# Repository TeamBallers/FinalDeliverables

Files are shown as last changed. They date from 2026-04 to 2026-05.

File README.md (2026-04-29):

# FinalDeliverables

The following explains the contents of this repository. Headings are directories or files located at a level associated with the size of the heading. For example, `designs` below is a first level heading and `code` below is a second level heading. `code` is a directory under `designs`.

# designs

## code
Contains all the code used in our project

### gyroscope_controller
This was used for testing the gyroscope camera cutting algorithm only. This code was not used in the final project. As it was not used in the final project, I only list relevant parts of the directory

#### camera_down_detector.py 
Contains the `CameraDownDetector` class, which was copied into the final project's `camera_client.py` file. IMU data can be passed to this class to initialize and update its readings, and can be queried for the new positions of the cameras.

#### calibrate.py
Used to get initial positions for the cameras

#### test.py
Can be run for an example of the output of the `CameraDownDetector` class

### mast3r-camera-client
This was the code ran on each of the Pis. It includes the `camera_client.py` script that captures and sends images, `camera_api.py` to start/stop the captures, `camera_api.service` to start the api on boot, and `setup.sh` to download requirements and enable the service. `downward_detector.py` contains a copy of the `CameraDownDetector` class from `gyroscope_controller`, as well as filtering classes `LogSampler` and `RatioSampler` to reduce noise from the predictions. 

### MASt3R-SLAM-API
This contains the MASt3R-SLAM code described at https://edexheim.github.io/mast3r-slam/ . Additionally, it includes a modified version of the API from the previous team at `image_receiver_api.py` and the API to run YOLO at `server/yolo_api.py`. `process_images.py` is used to run MASt3R-SLAM.

### ply_viewer
This repository contains the viewer that users will interact with. `viewer.html` contains the .ply viewer for viewing the models. `detection_popup.html` contains the viewer for live object detection.

### erms-object-detection
This repository was for testing and was not run in the final project. It includes testing infrastructure. `client_pi/test_yolo_pipeline.py` is a basic script to capture images and send them to an api that runs YOLO. The api is located in `server/yolo_api.py`. The viewer can be found in `viewer_test`.

### Usage instructions (not a directory)
Users should create a GPU VM with any Linux OS to act as the server. Install tailscale and add the server to your tailnet. In the root directory, clone `MASt3R-SLAM-API` and `ply_viewer`. In `MASt3R-SLAM-API`, follow the instructions in the `README.md` to set up your environment. 

On the three Raspberry Pis, install tailscale and add the devices to your tailnet. Clone `mast3r-camera-client`. Modify `camera_api.service` to use your server's tailnet IP. Run `bash setup.sh`. Run `sudo systemctl daemon-reload` and `sudo systemctl start camera_api.service` or reboot. 

Back on the server, find all hardcoded IPs in the html files and update them accordingly.

To run the server, use ```tailscale serve ~/ply_viewer &``` to expose the viewer files to the tailnet. Then 

```bash
cd MASt3R-SLAM-API
python image_receiver_api.py --continuous --copy ../ply_viewer/model.ply &
python server/yolo_api.py &
```

## schematics
Contains schematics and diagrams of our system, as well as 3d printing files for all stages of the project

## data
Contains various testing data used for reports

## data_sheets
Contains data sheets for purchased and used components

# reports
Contains all of our reports

# Hardware System Visuals & Measurements
Contains close-up reference images of the system and its assembly

# Videos.zip
contains a link to demo videos of our final project. Including the zip was 2GB and was taking too long.

# notebooks
contains our notebooks

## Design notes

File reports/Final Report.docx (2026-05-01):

Emergency Response Mapping Sphere

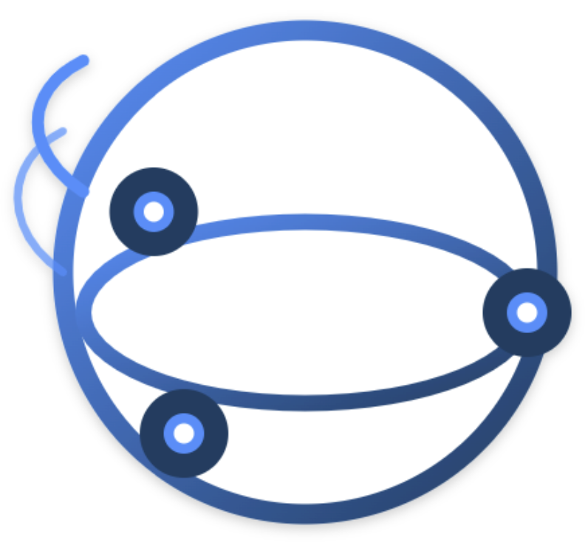
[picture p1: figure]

Final Report

Team ERMS

Brandon Le

Kiet Nguyen

Hai Yen Nguyen

Josh Wu

Antony Quach

Department of Computer Science and Engineering

Texas A&M University

Date 4/30

Table of Contents (Be sure to regenerate before submitting).

1 Executive summary (1-2 pages; 5 points) 3

1.1 Context 4

1.2 Project Goal and Objectives 4

1.3 Final Design Implementation and Pipeline 4

1.4 Project Verification Results 5

1.5 Team/Project Management 5

2 Project background (2-4 pages; 5 points) 5

2.1 Needs statement 5

2.2 Goal and objectives 5

2.3 Design constraints and feasibility 6

2.4 Literature and technical survey 6

2.5 Evaluation of alternative solutions 8

3 Final design (5-10 pages; 5 points) 9

3.1 System description 9

3.2 Complete module-wise specifications 10

3.2.1 Hardware 10

3.2.1.1 Microcontroller Operating System Setup 10

3.2.1.2 Adafruit ISM330DHCX IMU 10

3.2.1.3 Battery Selection 11

3.2.1.4 Power Distribution Board Usage 11

3.2.1.5 3D-Printed Shell 11

3.2.2 Software 11

3.2.2.1 Data Flow 11

3.2.2.2 Gyroscope and Camera Cutting 12

3.2.2.3 Master SLAM and Gaussian Splatting 12

3.2.2.4 Object Detection 12

3.2.2.5 System User Interface 13

3.3 Approach for design validation 13

4 Implementation notes (10-20 pages; 30 points) 14

4.1 System Overview 14

4.2 Mechanical Implementation: Throwable Ball Shell 14

4.2.1 Design goals and constraints 14

4.2.2 Shell geometry and layout 15

4.2.3 Camera and IMU Standoff and Mounting 15

4.2.4 Pi Mounting and Battery Support Standoffs 16

4.2.5 3D-printing process 17

4.2.6 Mechanical Assembly Procedure 18

4.3 Electrical 20

4.4 Embedded Software 20

4.4.1 Base OS and configuration 20

4.4.2 Tailscale VPN Network Setup 21

4.4.3 Camera Capture 21

4.5 Server-side 3D Model Generation and Object Detection 21

4.5.1 Data input 21

4.5.2 Object Detection Pipeline 21

4.5.3 MASt3R-SLAM Pipeline 22

4.5.4 Web-based viewer 23

4.6 Testing 23

4.7 Future Considerations 23

5 Experimental results (5-10 pages; 20 points) 24

5.1 Physical design 24

5.2 Multi-Camera Capture 25

5.3 Gyroscope and Camera cutting 26

5.4 SLAM Modeling and YOLO Object Detection 27

5.5 Camera Performance in a low-light environment 28

5.6 End-to-End System Functionality 28

6 User’s Manuals (5-10 pages; 20 points) 29

7 Course debriefing (2-4 pages; 10 points) 34

8 Budgets (2-4 pages; 5 points) 36

8.1 Detailed Cost Breakdown 36

8.2 Cost Narrative 36

8.3 Budget Comparison and Mass Production Estima 37

9 Appendices 37

10 References 37

# 1 Executive summary (1-2 pages; 5 points)

As you did with the proposal, the final report should start with an executive summary. In this section, you provide a brief overview of (1) the need, goal and objectives of the project, (2) the final design and implementation, (3) the results that were obtained, and (4) your experiences with team/project management. The intended audience of the executive summary is the program director at the institution/company that funded your project. Since the executive summary is a summary of the final report, it should be written last.

## 1.1 Context

Emergency response operations require rapid and accurate situational awareness, especially in hazardous environments where traditional methods are impractical or dangerous. First responders are routinely entering unfamiliar space such as structurally compromised buildings, active threat scenarios, and chemical spill sites, where visibility is often limited and conditions are very unpredictable. These challenges significantly increase the risk of injury, delay rescue efforts, and can lead to poor tactical decision-making in critical moments. Although current technologies such as drones, body-worn cameras, and robotic systems are used to support these operations, they frequently provide incomplete spatial information, suffer communication delays, or fail to function in confined indoor environments. Drones cannot navigate tight corridors, wheeled robots struggle with debris and rough surfaces, and stationary cameras offer limited field of vision. As a result, existing technologies do not sufficiently reduce operational risk or provide the level of real-time situational awareness necessary to ensure responder safety and mission success.

## 1.2 Project Goal and Objectives

The goal of this project is to build off of the previous team’s version of a throwable environment scanning device capable of capturing footage of an indoor environment with camera lenses and then reconstruct a 3D mapping using Gaussian splatting. Our objective includes: implementing an IMU sensor for intelligent power management by disabling ground-facing cameras, implementing SLAM algorithm for 3D reconstruction and improving accurate capturing, object detection to classify animate vs. inanimate objects, establishing WiFi connectivity for cloud-based processing, and validating performance against metrics similar to the previous team including sub-30 second deployment-to-visualization time.

Through this project, we expect that we will be able to create 3D models accurate to at least 10% of real measurements within 30 seconds of capturing images. We also plan to be able to identify and flag objects moving faster than 20 cm/s. Through these results, first responders will obtain comprehensive 3D situational awareness within seconds of deployment, enhancing tactical decision-making in active emergencies. The throwable format requires no specialized training or line-of-sight operation. Unlike 2D feeds, 3D reconstruction enables accurate spatial judgement for planning entry strategies, identifying routes, and locating victims or threats in possible hostage situations. At under $300 per unit for the throwable device using commercially available components, the system is substantially more affordable than specialized robotics, enabling broader deployment across agencies with limited resources. The server workstation can process multiple simultaneous deployments, supporting coordinated multi-room surveying. Beyond emergency responses, applications include building inspection, disaster search-and-rescue, and hazardous material incident response.

## 1.3 Final Design Implementation and Pipeline

Similar to the previous team’s design, the device consists of a spherical enclosure containing 3 wide-lens No-IR cameras inside, 3 microcontrollers consisting of a Raspberry Pi 4B and 2 Pi Zero 2 W’s, an Adafruit ISM330DHCX gyroscope module, a CMT Power Distribution module, a 5W 2.4A portable powerbank, and wireless networking that connects to a VPN. Once deployed, the operator can access the web GUI to access the model output, images with object detections, and commands to enable/disable the ball wirelessly. The shell’s design has been tweaked slightly from the previous team’s design to incorporate elements to support our changes to the hardware.

## 1.4 Project Verification Results

The product passed most of our tests regarding the reliability of the ball and its physical capabilities, but failed to provide a useful model in a satisfactory amount of time, taking about ~90 seconds in realistic usage to complete a model. It was concluded that the cameras in motion would not be able to take enough suitable photos to create a sufficient model through MASt3R-SLAM. The YOLO Object Detection exceeded our expectations, however. It was able to make important detections on live objects quickly and accurately. Even being able to make important distinctions in the dark or off of partial information. Even only a shoe is enough for the system to detect a person.

## 1.5 Team/Project Management

Throughout the project, the team followed standard engineering project-management practices, splitting into various teams focused on different tasks to develop multiple parts of the project at once, while also meeting twice a week to share progress and collaborate on ideas on how to move forward. We kept a collection of our documentation and work on a shared google drive, while pushing all project code to our shared GitHub. We also remained in constant communication via Discord.

# 2 Project background (2-4 pages; 5 points)

Describe the general scope of your project, and the specific problem that your project tackles. Go from general (e.g., search and rescue robotics) to specific (e.g., GPS navigation). This section (and all its subsections) can be expanded from those in the proposal.

## 2.1 Needs statement

Define the specific need that your project addressed. Articulate the need as an expression of dissatisfaction with the current situation. If the needs statement was revised during the semester (e.g., because the initial needs statement may have been too restrictive), please document the changes and provide a justification.

First responders routinely have to enter dangerous structures as part of their jobs. Hazards such as structural integrity, fire, or live threats slows them down during time sensitive missions and risks their lives. From 2018 to 2020, 87% of firefighter injuries occurred during structure fires, highlighting the significant dangers associated with indoor emergency response. Additionally, active shooter incidents last an average of only 12 minutes, leaving little time for responders to assess and secure a scene. Existing solutions are upwards of thousands of dollars and tend to require a skilled operator. These statistics demonstrate the urgent need for a device that first responders can deploy quickly to enhance safety and situational awareness in hazardous environments.

The previously designed Throwable Environment Scanner addresses this need but is lacking in some areas. Currently, its 3D mapping capabilities are not clear enough to allow users to be confident that all threats have been identified, demonstrating a need for improvements in threat identification. Furthermore, users may find it difficult to use the map, showing that a more intuitive user interface is needed.

## 2.2 Goal and objectives

As discussed in the proposal template, the goal is a brief, general, and ideal response to the needs statement. The need describes the current, unsatisfactory situation; the goal describes the future condition to which we aspire. The goal statement is so ideal that it would be difficult to decide when it was achieved. It rather establishes a general direction for the design mission. In contrast, the objectives are quantifiable expectations of performance. The objectives should also include a description of the conditions under which the design must perform. Again, if goal and objectives were revised during the semester, please document the changes and provide a justification for these.

The goal of this project is to enhance the Throwable Environment Scanner so that it can deliver high-quality 3D mapping directly to a first responder’s device while improving existing system efficiency.

The main objective of the system is to utilize onboard cameras to stream live video and reconstruct a 3D representation of the surrounding environment, improving situational awareness and enabling more effective threat detection. At the same time, the device must maintain its portability and durability to remain practical for field deployment. It will be limited to a maximum weight of 3 pounds and a maximum diameter of 7 inches, while also being capable of withstanding drops and collisions in hazardous conditions. The device must support 30 minutes of continuous operation at a minimum to ensure reliability during active incidents and be able to start up within 30 seconds to reduce delays. Additionally, the project must remain within cost constraints, with a maximum budget of $250 allocated for design iterations. The system must also provide threat identification in the environment to reduce mental load on users.

## 2.3 Design constraints and feasibility

Describe the constraints (e.g., technical, physical, economical, temporal) that you had to work with. Again, if these were revised during the semester, please document the changes and provide a justification.

One of the primary challenges of this project is ensuring that the first responders get an accurate representation of the environment with low latency. The 3D model generation and threat identification must take less time than traditional methods of ensuring safety in dangerous structures. Processing and reconstructing high-resolution spatial data requires significant computational resources, which may introduce latency and limit real-time usability. Additionally, the device must be engineered to withstand strong and repeated impacts, as it is designed to be thrown into hazardous environments. This requires a durable outer structure that protects internal components without exceeding weight and size constraints. Finally, the hardware must support complex transmission logic capable of delivering high-resolution images and mapping data quickly and reliably. Efficient data compression, wireless communication stability, and low-latency streaming will help maintain performance under emergency response conditions. Given that the durability and portability objectives of the system have already been tested, all objectives can be completed fully if threat detection and environment reconstruction algorithms are sufficiently fast and camera data quality is sufficiently accurate.

## 2.4 Literature and technical survey

Describe prior research and development efforts that were specifically related to your project. As stated in the proposal template, this is not meant to be a comprehensive survey of an engineering discipline, but a concise overview of the most significant results that are tightly related to your project. As a guideline, this section should include a review of not less than five commercial products or research projects. This review should conclude with a statement that explains the extent to which your final design is related to these other products/projects (e.g., is it better? or faster? or cheaper? does it target a new niche market?). Expand this section if additional references were found to be relevant during the semester.

While the Throwable Environment Scanner is not the first product to solve the problem of scouting hazardous indoor environments, it does improve on existing solutions by being cheaper and requiring little training to produce a 3D map. Other products might have one of these features, but none of them combine them all. By being cheap and requiring little training, it can be easily integrated into most teams entering dangerous rooms. The 3D model visualization can allow operators to view any aspect of the environment in just a few seconds after the ball has rolled, improving decision making.

Solution | Description | Pros | Cons
The Brinc Ball | Throwable communication device that functions as a telephone | - Capable of communicating with people inside dangerous area | - Does not record video, scan environments, or generate maps
Recon Robotics Throwbot | Compact wheeled surveillance robot for live video and audio | - Extremely durable (30-ft drops, 120-ft throws) - Up to 60 minutes of battery life | - Requires training to operate and has only one camera angle - Obstructed terrain can limit mobility
Flyability Elios 3 (Surveying Payload) | Collision-tolerant indoor drone designed for inspection, mapping, and 3D environment reconstruction | - Can actively navigate complex or obstructed spaces | - Not throwable, requires skilled operation, and is high-cost industrial hardware
Bouncing Image Explorer 360 | Throwable 360° tactical ball camera with live phone streaming (WiFi & Cellular) | - Compact, durable, and capable of window impact deployment | - No depth reconstruction (manual viewing only); high cost ($4k–$7k)
Squishy Robotics Stationary Robot | Throwable or aerial-deployable multi-sensor response device | - Highly impact-tolerant; designed for hazardous and disaster environments | - Stationary operation; complex and high-cost system

## 2.5 Evaluation of alternative solutions

Discuss the alternative designs that were considered throughout the project. Analyze the pros and cons of each of these designs, and justify your decision to opt for a particular solution. You may have found additional alternatives aside from the ones in the proposal, so make sure you include all.

- Drones
  - Pros
    - Provide overhead views of environments, including inaccessible or elevated areas.
    - Already commercially available and supported by existing technology.
  - Cons
    - Hard to operate in enclosed areas
    - Requires significant skill from a trained operator
- Grounded Robot
  - Pros
    - Can have mobility in enclosed areas
    - A lot of them carry very sophisticated mapping and recording systems
    - Already being used by some first responders and military units
  - Cons
    - Mobility issues if the ground is obstructed/uneven
    - Usually large and hard to carry. Not very portable
- Throwable Communication Ball
  - Pros
    - Cheap
    - Small
    - Durable
    - Remote communication is highly useful for many areas, not limited to search and rescue, crisis intervention, disaster response, and negotiation/de-escalation
  - Cons
    - Cannot visualize an environment
    - Requires a conscious and willing corespondent; does not work for search and rescue of unconscious people
- Body Cameras
  - Pros
    - Cheap
    - Lightweight
    - Already exists in the market
  - Cons
    - Require a human in the environment, which could be hazardous
    - Remote operators cannot can only view the direction the wearer observes
- 360° Cameras
  - Pros
    - Views the entire environment at once
    - Lightweight and portable
    - Already exists in the market
  - Cons
    - Requires a mount or transportation device to be placed somewhere

# 3 Final design (5-10 pages; 5 points)

## 3.1 System description

Please provide a description of the overall system. This description should include a high-level block diagram and a functional description of the different parts and interfaces in your final system. If any of these were revised after the CDR, please document the changes and provide a justification.

The final system is a throwable device designed to capture and reconstruct a 3D view of an environment. It is built as a spherical enclosure containing three cameras, embedded computing units (Raspberry Pi Zero 2 W and Raspberry Pi 4B), an inertial measurement unit (IMU), a battery, and a power distribution unit.

Once deployed, the cameras capture wide-angle images from different viewpoints. Each camera is connected to its own embedded unit, which handles image capture and transmits the data to a remote server. The IMU is used to determine the orientation of the device, allowing the system to identify downward-facing cameras and reduce unnecessary power consumption. The power distribution unit supplies power to all embedded components.

In the original design proposed during the Critical Design Review (CDR), a camera multiplexer was used to switch between multiple cameras on a single processor. However, this approach introduced delays due to sequential image capture. In the final design, this was replaced with multiple Raspberry Pi Zero 2 W devices and a Raspberry Pi 4B, each controlling a single camera. This allows all cameras to capture images simultaneously, improving overall system performance and image coverage.

The captured images are transmitted to a remote server through the Texas A&M IoT (TAMU IoT) network. To enable reliable and secure communication between distributed devices, the system uses Tailscale, a mesh VPN that allows each embedded unit and the server to communicate over a private network as if they were on the same local system.

On the server side, upon receiving the data, the images are synchronized and processed using 3D Gaussian Splatting to generate a 3D model of the environment. At the same time, a YOLO-based object detection model is used to identify objects within the images.

The resulting outputs, including the reconstructed 3D model and detected objects, are transmitted to an operator interface, where they can be inspected and analyzed for situational awareness and decision-making.

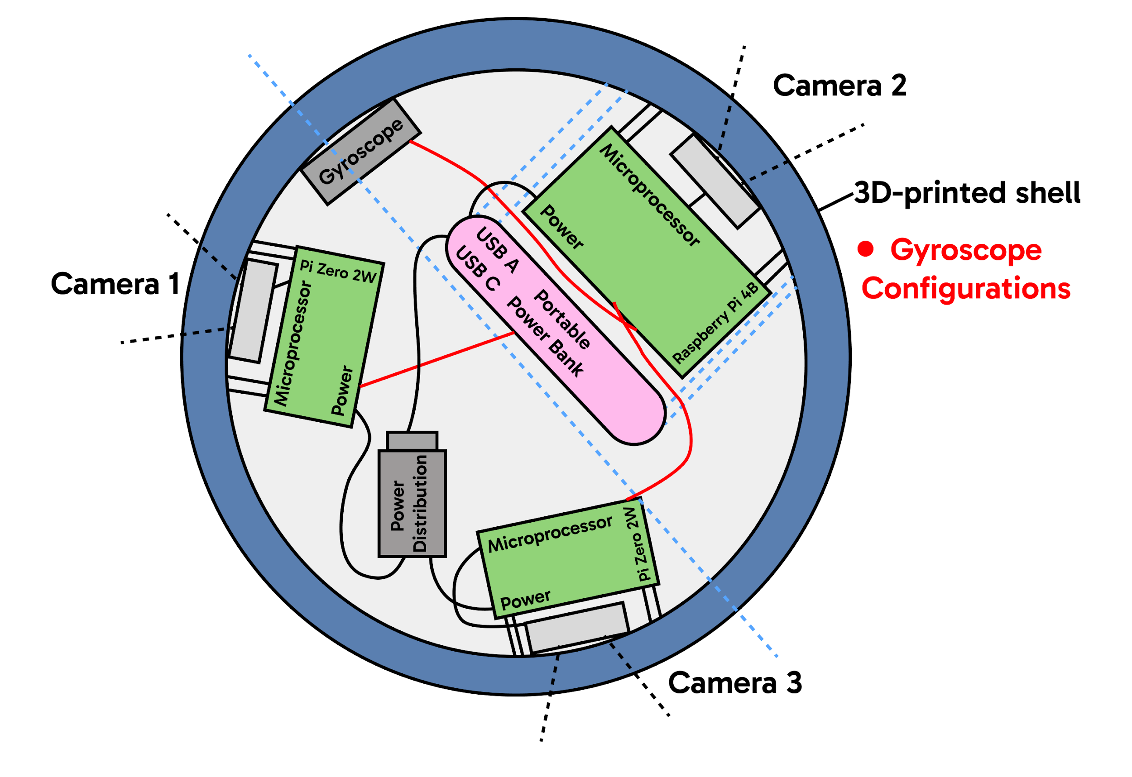
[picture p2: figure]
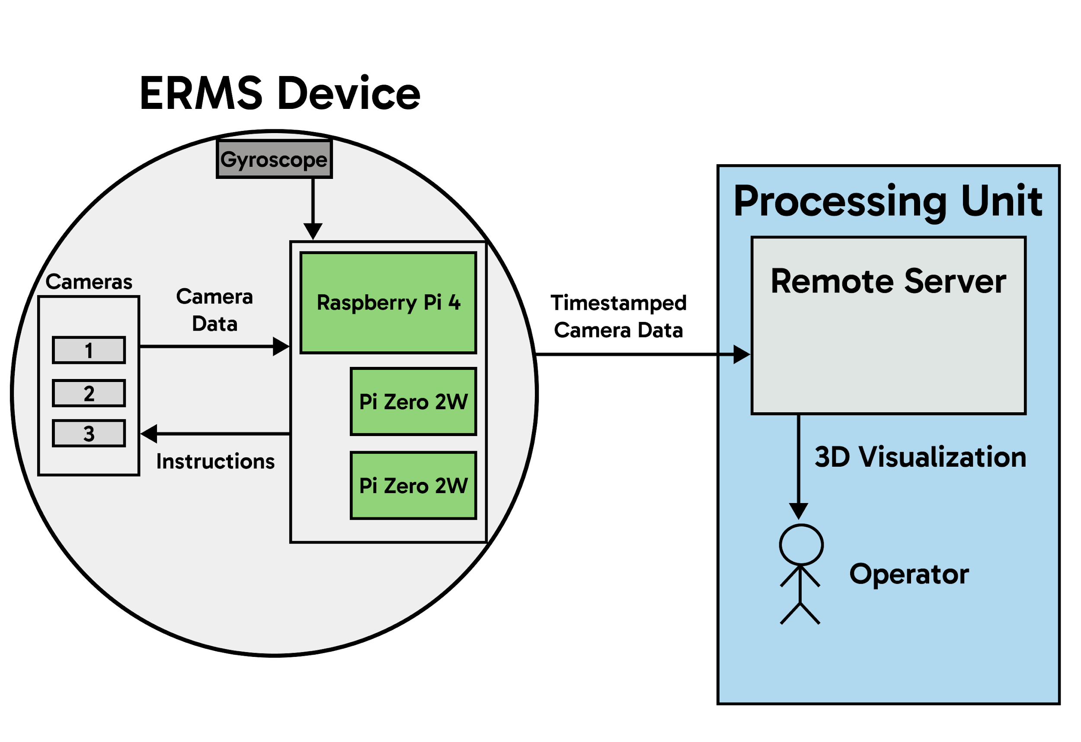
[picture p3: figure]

Figure 3.1.1: Final System High Level Diagram Figure 3.1.2. Internal layout of system

components within the spherical enclosure

## 3.2 Complete module-wise specifications

Provide a detailed design of each subsystem (both hardware and software), including

- Circuit and logic diagrams
- Interfaces and pin-outs
- Timing diagrams and waveforms
- Software processes with their inputs and outputs
- Complete parts list

If any of these were revised after the CDR, please document the changes and provide a justification.

### 3.2.1 Hardware

#### 3.2.1.1 Microcontroller Operating System Setup

The hardware architecture consists of three separate microcontrollers using a Raspberry Pi 4B, and two Raspberry Pi Zero 2 W’s. This setup ensures parallel processing and true simultaneous camera streaming to ensure environmental capturing from multiple angles at once.

#### 3.2.1.2 Adafruit ISM330DHCX IMU

The IMU is used to approximate the rotation of the ball to determine if any cameras are facing downward. If any cameras are detected to be facing downward, they are temporarily disabled and they do not upload images to the server. This helps save time and processing power, as images where the camera is facing downward are likely to not be useful.

#### 3.2.1.3 Battery Selection

The powerbank we selected was a Miady 5000mAh Mini Portable Charger, 5V 2.4A USB-C. This powerbank is able to fit nicely into the shell while providing sufficient power at 5V and 2.4 A. It is also capable of powering two devices simultaneously using both of its ports.

#### 3.2.1.4 Power Distribution Board Usage

The CMTPD Board takes an input through USB-C and regulates it to the selected voltage for output. In our case, the desired voltage output is 5V for the Raspberry Pi Zero 2W boards. We connected two micro-USB cables with pig-tailed ends directly to the output of the CMTPD Board. From there we connect the micro-USB cable to the Raspberry Pi Zero 2 W boards. This way the components are kept modular.

#### 3.2.1.5 3D-Printed Shell

The 3D-Printed Shell houses all electronic components and shields them from external forces like heat and impacts. It has 3 camera holes equidistant from one another ensuring each camera makes full use of their 120° field of vision. It uses a series of mating flanges along the equator to secure itself together. Inside, each electronic component has its own set of standoffs where each component can be secured using M2.5 screws. The standoffs for the Raspberry Pi 4B are noticeably thicker to support the larger board. Various supports are also added to prevent the internal battery from causing damage to the Raspberry Pi 4B.

### 3.2.2 Software

#### 3.2.2.1 Data Flow

The system data flow is built on a Tailscale VPN network, which establishes a secure and encrypted communication tunnel between the throwable device and the remote server. This approach enables reliable communication even when devices are connected to different Wi-Fi networks, ensuring flexibility and robustness in diverse deployment environments.

The data pipeline operates in two main stages: device-to-server data transmission and server-to-operator delivery.

On the device side, the Raspberry Pi camera units generate timestamped image frames during operation. These frames are compressed as JPEG images and downsampled to reduce bandwidth usage before being transmitted to the remote server using HTTP POST requests through a FastAPI endpoint. The server receives and stores these images in a dedicated directory, where they are monitored for downstream processing.

On the server side, incoming images are processed by two independent pipelines: a YOLO11s object detection module and a MASt3R-SLAM reconstruction pipeline. These modules operate on the same incoming dataset to generate both semantic object information and a 3D representation of the environment.

Processed outputs, including the reconstructed 3D model and annotated detection results, are served to the operator interface over HTTPS through the Tailscale network. The interface continuously polls the server for updates, enabling near real-time visualization of both spatial reconstruction and detected objects.

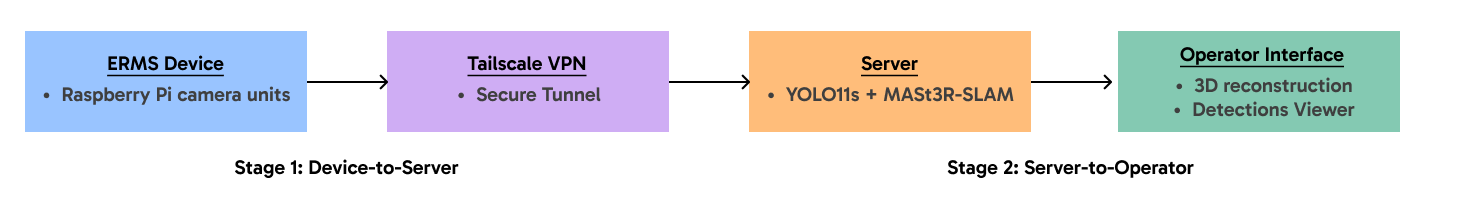
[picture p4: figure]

Figure 3.2.2.1: High-Level Diagram of Data Flow

#### 3.2.2.2 Gyroscope and Camera Cutting

The purpose of this subsystem is to detect the device’s orientation in real time using a gyroscope, enabling the system to reduce unnecessary processing and improve overall power efficiency. By identifying which camera is facing downward, the system can selectively manage image capture and processing, avoiding the use of frames that are less useful for reconstruction. The implementation relies on a gyroscope that continuously streams orientation data to the main Raspberry Pi controller over an I2C interface during operation. The controller interprets this data to compute rotation updates and determine which camera is oriented downward. It then communicates this information to the other Raspberry Pi units using a GPIO-based single-bit flag. Each Pi reads this flag during image capture and uses a timing window to assess whether its camera was facing downward during the critical portion of the capture process, allowing the system to make informed decisions about which images to retain or discard.

#### 3.2.2.3 Master SLAM and Gaussian Splatting

The MASt3R-SLAM subsystem is responsible for estimating camera motion and generating a 3D reconstruction of the environment using the captured image data. The system processes a sequence of images collected as the device moves through the environment, enabling spatial understanding of the scene.

Images are received from the capture subsystem and stored in a shared directory for processing. Using a MASt3R-SLAM implementation, the system performs feature matching across multiple images to estimate camera poses, including position and orientation for each frame. This allows the system to determine where each image was captured and reconstruct the surrounding environment.

The estimated camera poses and associated image data are then used as input to a Gaussian Splatting pipeline. This process converts sparse feature correspondences into a dense 3D representation by projecting image information into a continuous spatial model.

The reconstruction process is executed on a remote server due to the computational demands of SLAM and Gaussian Splatting. The generated 3D model is exported as a ply file and made available to the operator interface for visualization.

#### 3.2.2.4 Object Detection

The object detection subsystem is responsible for identifying and classifying objects within the captured environment. This is implemented using the YOLO11s object detection model (YOLO “You Only Look Once” variant), which performs real-time object detection on incoming image frames. Object detection is carried out on the remote server using the same images processed by the MASt3R-SLAM pipeline, ensuring consistency between spatial reconstruction and semantic understanding of the scene.

As illustrated in Figure 3.2.2.4 below, the object detection pipeline begins with image capture on the Raspberry Pi camera units. The captured images are transmitted to an Image Receiver API on the remote server via HTTP POST requests, where they are stored in a designated incoming images directory.

Rather than images being directly forwarded, the YOLO processing server continuously monitors this directory for newly added images. When new images are detected, the server automatically processes them and performs object detection using the YOLO11s model. The model generates bounding boxes, class labels, and confidence scores for all detected objects in each frame.

All detections produced by the model are preserved in the server-side output. However, a higher-level filtering step is applied at the image level before visualization. Only images containing at least one detected living entity, such as a person or animal, are forwarded to the detection viewer. This design reduces visual clutter by preventing frames without relevant entities from being displayed, while still retaining full detection results on the server for logging and analysis.

Figure 3.2.2.4: YOLO Object Detection Pipeline

#### 3.2.2.5 System User Interface

The system provides a web-based interface for control and visualization of the captured and processed data. The interface is designed to be user-friendly and requires minimal technical expertise, allowing operators to interact with the system through a standard web browser.

Through this interface, a navigation bar at the top allows the user to start or stop the Raspberry Pi camera client using a single button, simplifying system operation. A real-time status indicator is also included to display the current system state, such as loading, ready, or actively processing data during 3D reconstruction.

In addition to control functionality, the viewer displays processed outputs from the backend pipeline. This includes the 3D reconstruction generated by the MASt3R-SLAM and Gaussian Splatting pipeline, as well as object detection results produced by the YOLO11s model, which are accessible in a separate detection tab. The detection results are rendered with bounding boxes and class labels overlaid on the corresponding images.

This enables simultaneous visualization of both spatial structure and semantic information, allowing operators to inspect the reconstructed environment while identifying detected objects in real time.

The interface is accessible through any standard web browser and communicates with the backend system over the Tailscale network, requiring no additional software installation beyond network access.

## 3.3 Approach for design validation

How did you test your system to ensure that it did what it was designed to do? If these validation procedures were revised during the semester, please document the changes and provide a justification.

- Camera Quality: The images taken by the camera should be checked to ensure that they clearly picture the environment and objects in the images are easy to identify. The photos captured by the camera will be compared to the environment to ensure accuracy.
- Model Quality: The 3D model created by MASt3R-SLAM is based off of the images collected by the ball and thus the environment it was thrown in. The model created by the server will also be compared to the environment to ensure accuracy. The generation will also be timed as time taken is also an important factor.
- Wireless transmission: Because the ball is intended to be used remotely, the ball must be capable of transmitting wirelessly from a distance through walls and objects. To test this, we plan to operate the ball through 10m of obstacles and evaluate for latency and data loss.
- User interface: Because our tool is meant to have little operator training required, the user interface must be intuitive and easy to use. To test this, we will use third parties as operators. While the test operators use the system, we will observe them and ask about their experience.
- Mapping algorithms: If the 3D environments are not accurate to the real environment, operators may make decisions based on incorrect information. We will compare the generated environments against measurements of the real one to ensure accuracy.
- Live object identification: Hidden live objects may not be easy for operators to identify. To ensure the system can identify live objects, we will operate it in an environment with humans and or animals, in varying degrees of hiddenness, and compare the generated flagged objects to the real ones to ensure that the system does accurately flag live or moving objects.
- Lifespan test: The device must operate for long enough that it can be used to explore multiple environments and to monitor changes in environments. The ball will be fully charged and operated until it runs out of battery to determine its lifespan.

# 4 Implementation notes (10-20 pages; 30 points)

This is the single most important section in the final report. It should contain “engineer's notes” that would allow a reasonably skilled engineer to understand, reproduce and modify your group’s products.

Remember that figures should include labels and captions and be referenced directly in text. An example of a figure with a label and caption can be seen in Figure 1. Additionally, tables should also be labeled and captioned and a direct in text reference. Table 1 shows an example of a labeled and captioned table. Labeling and caption may be painful to do in Google Docs as was done here, but it should be easier in MS Word, and significantly easier in LaTeX.

## 4.1 System Overview

At a high level, the system consists of three tightly coupled subsystems:

1. Throwable sensor ball – a 3D-printed spherical enclosure that houses 3 wide-lens No-IR cameras inside, 3 microcontrollers consisting of a Raspberry Pi 4B and 2 Pi Zero 2 W’s, an Adafruit ISM330DHCX gyroscope module, a CMT Power Distribution module, a 5W 2.4A portable powerbank, and wireless networking that connects to a VPN. All electronics are rigidly mounted to survive impact when the ball is thrown into a room.
2. Network and control plane – each Pi automatically joins a Tailscale VPN and exposes a REST API and image stream to a central processing server. Time-stamped frames and metadata are transmitted over Wi-Fi.
3. Reconstruction and visualization server – a high-performance cloud server with an NVIDIA GPU that receives images, scans images for relevant objects, and reconstructs the environment using Gaussian-based methods. The resulting images and 3D model are uploaded to a web viewer where the results can be viewed freely and the ball can be interacted with remotely.

Refer to Figure 3.1.1 and Figure 3.1.2 on page 10 for a visual description.

## 4.2 Mechanical Implementation: Throwable Ball Shell

### 4.2.1 Design goals and constraints

The shell needs to:

- Protect internal hardware from external impacts and fire damage
- Reliably hold each internal component in place. The gyroscope especially must be kept in one spot relative to the shell so that it can detect the rotation of the ball correctly
- Provide unobstructed fields of view for three wide-angle cameras with minimal occlusion from the shell
- Must be easy to maintain, using standard components, and the inside should stay accessible
- Must be secure enough to stay closed even under direct impacts
- Stay within size and mass limits to preserve throwability (≤ 7 inches diameter and ≤ 1 pound weight)

These constraints drove the geometry of the shell, internal standoffs, and mounting surfaces.

### 4.2.2 Shell geometry and layout

The outer shell is a two-piece sphere printed from ABS 3D printing filament. ABS was chosen for its combination of impact resistance, moderate flexibility, and good heat resistance, which protects the electronics from both mechanical shocks and self-heating.

- Outer diameter: ~160 mm
- Wall thickness: ~5 mm (varies slightly with local features and standoffs)
- Joining method: mating flanges along the equator with a screw pattern and alignment features so the two halves always close in the same orientation.

Three circular camera windows are placed along the equator at 120° intervals. Each window is backed by a planar “cut” into the sphere: locally, the spherical surface is replaced by a flat patch where the camera PCB and lens mount. These tangent planes simplify alignment and ensure each camera looks roughly outward along a direction 120° apart from the others. This retains the same external design from the previous team.

### 4.2.3 Camera and IMU Standoff and Mounting

Each Raspberry Pi Camera Module 3 Wide has a rectangular PCB (~25 × 24 mm) with four mounting holes near the corners. We designed matching standoffs directly into each planar camera patch:

- Standoff layout: rectangle matching the camera PCB hole pattern (roughly 18–20 mm × 18–20 mm, measured from the actual board).
- Standoff outer diameter: 4.75 mm.
- Pilot hole diameter: 2.2–2.3 mm, sized for M2.5 self-tapping or machine screws.
- Height: enough to bring the PCB flush with the planar surface while keeping the lens protruding slightly beyond the outer surface, ensuring the glass is not recessed where it could see the edge of the shell.

The Adafruit ST ISM330DHCX IMU also needs to be secured in one spot relative to the ball

- The IMU’s mounting holes have the same measurements as the camera standoffs, so the same process can be applied to the IMU
- Positioning the IMU at the edge of the ball around the equator provides a convenient point of access for wires
- This can be seen in Figure 4.2.2

In SolidWorks, the workflow is:

1. Create a reference plane tangent to the sphere at the camera location.
2. Sketch the standoff pattern on this plane using the measured hole spacing.
3. Extrude the four cylinders inward toward the sphere’s center until they nearly touch the inner wall (leaving ~1 mm clearance).
4. Cut the internal pilot holes through the standoffs.
5. Cut a circular opening in the outer shell to match the camera lens shroud.

This retains the same measurements and workflow of the previous team, as we retained most parts of their design.

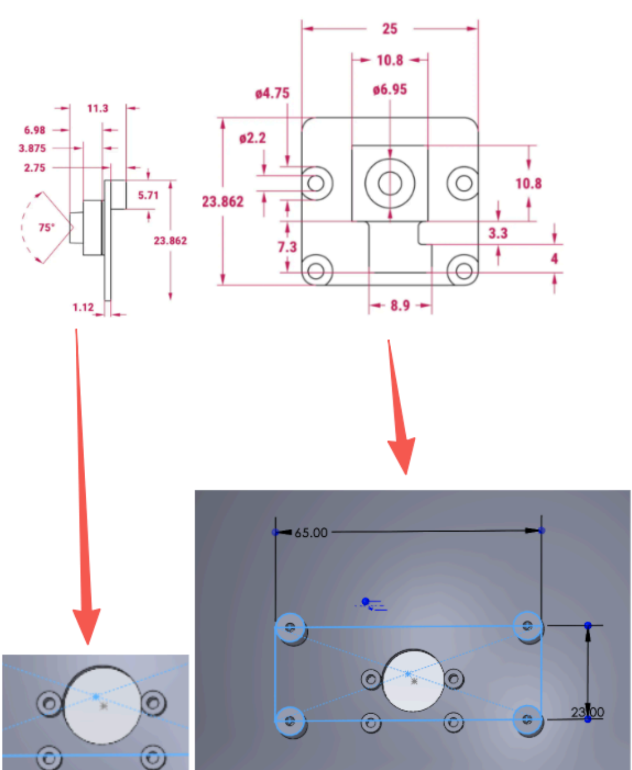
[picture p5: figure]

Figure 4.2.1: Translation of the Raspberry Pi camera module and Pi PCB dimensions into the SolidWorks mounting sketch. The top drawings show the manufacturer-provided mechanical dimensions of the camera module and its PCB, including the 4.75 mm mounting pads and 2.2 mm screw holes. Using these measurements, the bottom images define the corresponding bolt-circle and standoff locations on the spherical shell in SolidWorks, creating a 65 mm × 23 mm rectangular pattern of screw pillars that matches the actual board hole spacing.

During assembly, cameras are secured using M2.5 screws, and the CSI ribbon connects to the nearest Raspberry Pi Microcomputer.

### 4.2.4 Pi Mounting and Battery Support Standoffs

Below the equator, we designed a second set of internal mounts:

- A Pi mounting shelf – a rectangular boss (≈ 66 × 31 mm) located on an internal tangent plane, extruded ~3 mm from the inner surface. Each Pi Zero 2 W rests on this shelf.
- The Pi4B receives its own mount on the shell with only one camera opening. The Pi4B is much bigger so the following accommodations must be made:
  - The Pi4B has its mounting holes spaced at 58mm x 49mm rather than the zero’s 58mm x 23mm, so the standoffs must be spaced 13mm further on both the lower and upper ends.
  - The Pi4B also has additional ports to the side of the mounting holes that must be accounted for. Moving these standoffs to the opposite side. ~15mm is sufficient.
  - The Pi4B must also rest further from the outside of the shell as it is larger in width and length. To accommodate we must raise the standoffs to ~10mm higher. To support these longer standoffs, they should be thickened to increase the amount of stress they can handle. ~5mm in radius is sufficient.
  - These can be seen in Figure 4.2.2
- Four M2.5 standoffs with holes similar to the camera standoffs fasten each Pi. The pi boards are arranged such that the micro-SD card slot and USB ports remain minimally accessible when the ball is opened.
- The standoffs are positioned so that each Pi is roughly behind its corresponding camera, minimizing CSI ribbon length and cross-overs.

The Powerbank we used has the following dimensions:

- 3.6"L x 2.4"W x 0.5"Th (91.44mm x 60.96mm x 12.7mm)

To support powerbank in, we added supports that would hold the powerbank above the Raspberry Pi4B. This helps in the scenario where the powerbank would have otherwise fallen onto the Pi4B and possibly have damaged it or any of its wire connections. These should be spaced according to the powerbank’s dimensions listed above. These supports should also be ~45mm tall to clear the Pi4B. These can be seen in Figure 4.2.2

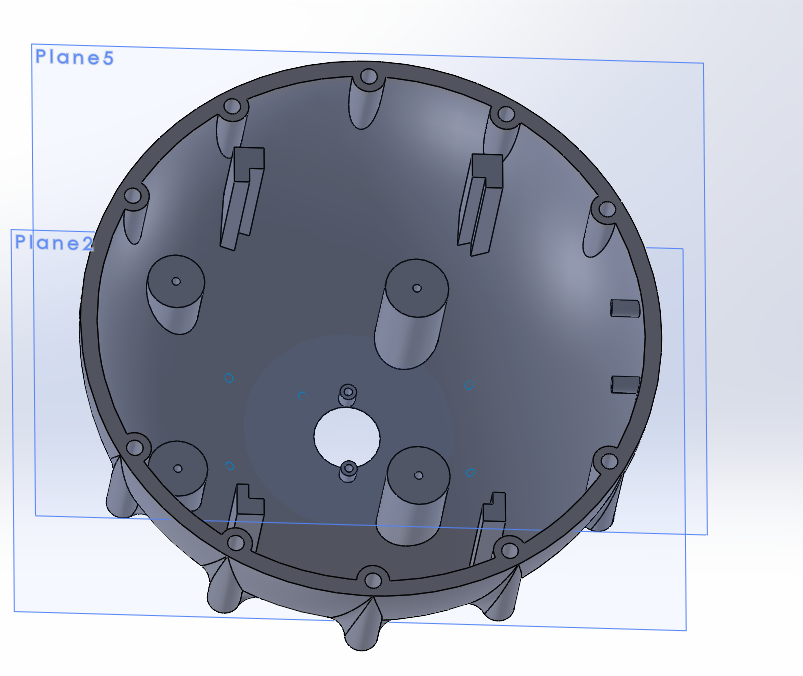
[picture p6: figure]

Figure 4.2.2: Final CAD file of updated shell design. This half accommodates the Raspberry Pi4B, the Adafruit ISM330DHCX IMU, and offers stands for the powerbank. It should be noted that the standoffs for the Raspberry Pi4B are noticeably thicker to better support and absorb impact.

### 4.2.5 3D-printing process

For reproducibility, we document the print settings used:

- Printer: Creality K1 Max (or similar Low Fidelity Machine at ≥300 mm build volume).
- Material: 1.75 mm ABS.
- Layer height: 0.2 mm for outer surfaces; 0.28 mm is acceptable for internal test prints.
- Nozzle diameter: 0.4 mm.
- Infill: 20–30 % gyroid or cubic, with 4–5 perimeter walls. More shells near the equator to stiffen the joint region.
- Print orientation: each half printed with the equator side down on the build plate. This maximizes strength in the radial direction and keeps camera surfaces clean.
- Bed temperature: 100 °C; nozzle temperature: 245–250 °C (tuned to filament).
- Enclosure: closed printer or external enclosure is strongly recommended to prevent ABS warping and layer separation.

This retains the same process done of the previous team, as we retain most of their design.

### 4.2.6 Mechanical Assembly Procedure

1. Prepare mechanical parts

- Clean 3D-printed halves; chase all pilot holes using a 2.3 mm drill to ensure smooth screw insertion.
- Tap camera and Pi standoffs if using machine screws, or use self-tapping M2.5 screws.

2. Install camera modules

- Attach each Raspberry Pi Camera 3 Wide to its standoffs using four M2.5 × 6 mm screws.
- Route each CSI ribbon inward through its slot. Secure cables with small adhesive clips or printed cable guides to avoid fatigue under impact.

3. Install Pi Zero boards

- Mount a Pi Zero 2 W onto each internal shelf of the half with two camera holes, aligned so the CSI connector faces its camera cable.
- Connect CSI ribbons, ensuring no severe bends and a bit of slack for shock absorption.
- Optionally add small foam pads between Pi and shell to damp vibrations.

4. Install Pi 4B board

- Mount the Pi 4B onto the half with the single camera hole with thicker standoffs, with the CSI connector connected to the camera below it and ensure there is no severe bend and a bit of slack for shock absorption.
- Optionally add small foam pads between Pi and shell to damp vibrations.

5. Connect Wires and Powerbank

- Using the Micro-USB power cables connected to the CMTPD board, connect each Pi Zero 2 W to the powerbank. Connect the Pi 4B to the powerbank with its own USB-C wire.
- To reduce wire clutter, wrap and arrange the wires around internal components and keep them bundled together.
- Seat the powerbank above its installed support beams and surround it with electronically safe packaging foam to reduce movement and vibrations

6. Close the shell

- Align alignment pins on the two halves.
- Route any remaining cables so they are not pinched in the seam.
- Fasten the equator screws (e.g., a ring of M3 screws spaced every 30–45°) and mark one side as “IMU” so that it is known which side the IMU’s position starts during initialization.

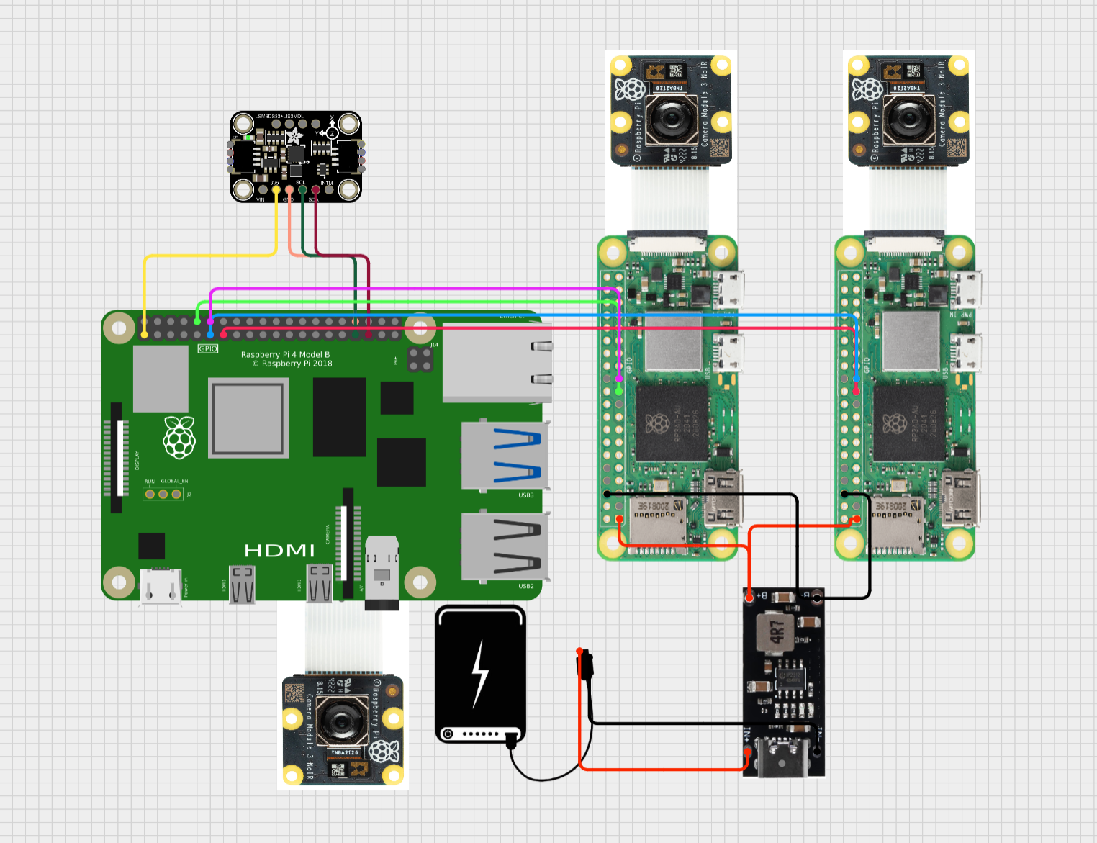
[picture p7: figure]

Figure 4.2.3: Final Schematic of hardware setup with connections.

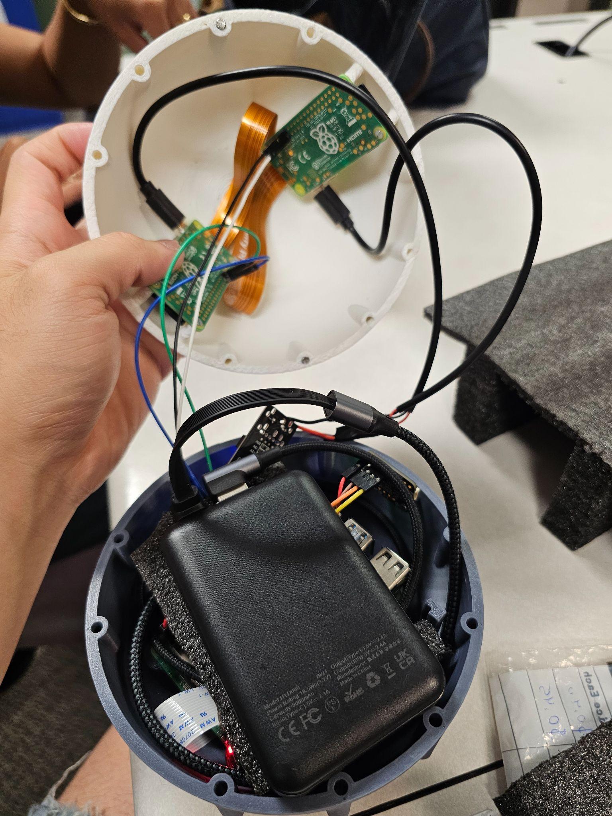
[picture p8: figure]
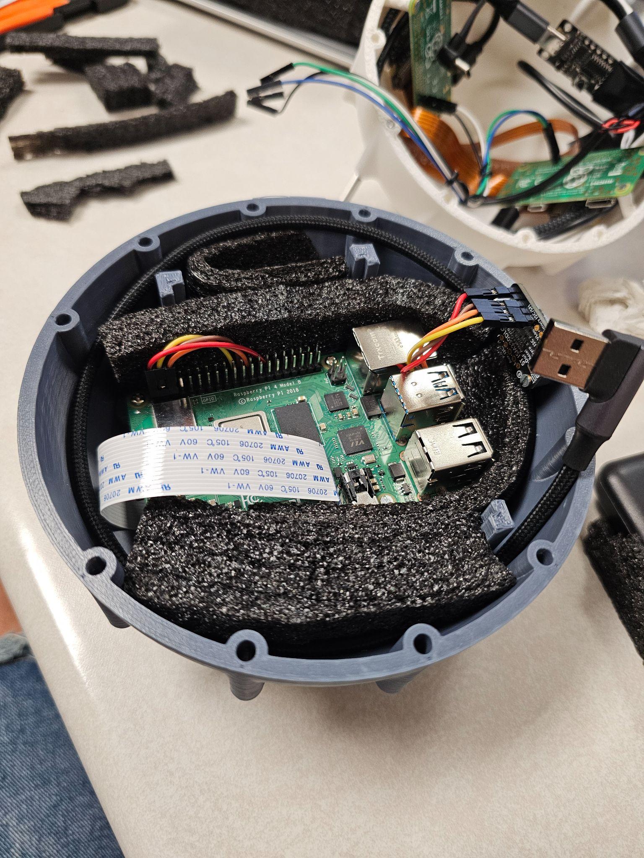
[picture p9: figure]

Figure 4.2.4: Bottom Half assembled while connected to Top Figure 4.2.5: Bottom Half assembled without battery

## 4.3 Electrical

The electronics in the ball are kept modular and simple, using basic components available commercially for ease of use and replacement. The flow of electricity is as follows

1. 5W 2.4A Powerbank
2. Using two different wires:
  a. A USB-A to USB-C wire directly connects to the Raspberry Pi 4B
  b. A USB-C to USB-C wire directly connects to the CMTPD Board for power distribution
3. The CMTPD Board accepts a USB-C input and is directly soldered to two Micro-USB cables limited at 5V. These connect to both Raspberry Zero 2 W modules.

It should be noted that while the Raspberry Pi 4B has overvoltage protection, the Raspberry Pi Zero 2 W boards do not. While the CMTPD Board should maintain a 5V output, if for any reason the voltage manages to rise above 5V for a short period of time, it can damage the Raspberry Pi Zero 2 W boards.

## 4.4 Embedded Software

Each Raspberry Pi board runs a lightweight Linux system meant to process and upload camera data as fast as possible.

### 4.4.1 Base OS and configuration

1. Install the latest version of the Raspberry Pi OS Imager software from the official website.
2. Select Pi model
  a. Select Use Custom OS
  b. Search for Raspberry Pi OS Lite (32-bit Debian Trixie)
3. Configure username, password, initial Wi-Fi/Network connection, and enable SSH.

*When using a hotspot, it should be configured to a teammate that has an android phone due to the fact that an android hotspot setting allows the user to view devices connected to hotspot, and also its IP.

*Each Pi is given a unique and differentiable host name (rpizero2w1, rpizero2w2, rpi4b)

4. Once the SD card has been successfully written, eject from device and insert into Pi.
5. Ensure that the configured Wi-Fi/Hotspot/Network is already turned on before powering the Pi on.
6. To connect to the Pi for headless mode:
  a. Connect laptop or PC to configured hotspot/network.
  b. Plug the Pi to the power source and wait for at least 2 minutes for it to fully boot.
  c. Open Powershell and SSH to the Pi:

>> ssh raspberrypi@<raspberrypi’s IP>

  d. Enter the configured password.
  e. Update the system:

>> sudo apt update && sudo apt upgrade -y

  f. To enable camera interface, run the command:

>> sudo raspi-config

  g. Navigate to 3 Interface Options - Configure connections to peripherals
    i. Enable the following: I4 SPI, I5 I2C
    ii. Select Finish
  h. Upon completing these steps, the Pi is now successfully set up with camera interface enabled, with the next step being to set up Tailscale VPN Network to allow easy access regardless of what network the remote devices are connected to.

### 4.4.2 Tailscale VPN Network Setup

We use Tailscale to create a secure mesh network between the Pis and the server:

1. Install Tailscale (curl https://tailscale.com/install.sh | sh).
2. Authenticate each Pi to the team’s Tailscale account and tag them appropriately.
3. Configure Tailscale to start automatically on boot.
4. Verify that each Pi can ping the server’s Tailscale IP address even when connected to different physical Wi-Fi networks.

This setup allows deployment in any Wi-Fi environment that provides outbound internet, making it heavily convenient for microcontroller access regardless of what network the user device (laptop, PC) is on.

### 4.4.3 Camera Capture

Each camera runs our own camera client. This can be set up using the following process.

1. Clone the mast3r-camera-client repository onto the corresponding Raspberry Pi
2. Run the setup script with “sudo bash setup.sh” to install required dependencies
3. Start the service using “sudo systemctl start mast3r-camera”

The server will need to be configured to your server’s IP address. Please consult the GitHub and READ.ME for more information.

The Raspberry Pi 4B will also run the gyroscope controller. Similarly clone the gyroscope_controller repository onto the Raspberry Pi 4B and use the camera_down_detector.py.

## 4.5 Server-side 3D Model Generation and Object Detection

The server is an Amazon Cloud Computing service with GPU processing. It receives images from each Pi, and uses them for 3D Model generation and object detection. If using a cloud server, ensure it has the proper CUDA version for your code.

### 4.5.1 Data input

Using Tailscale VPN Mesh Networking, we can establish a secure, encrypted tunnel between the ball and the server. Using this method allows us to connect the ball and server across different Wi-Fi networks. Using FastAPI, we send timestamped camera frames that are compressed and downsampled to save processing power. Images from the ball are stored in an “incoming_images” folder where they are used for both object detection and MASt3r-SLAM.

### 4.5.2 Object Detection Pipeline

The object detection subsystem operates as a server-side processing pipeline that analyzes incoming image data using the YOLO11s object detection model. The pipeline is designed to process images asynchronously as they are received from the Raspberry Pi capture nodes.

The incoming images are first stored in a designated directory (incoming_images/) by the image receiver API. The YOLO processing server continuously monitors this directory for newly added files. When a new image is detected, it is automatically loaded and passed to the YOLO11s model for inference.

During processing, the model analyzes each image and generates detection outputs consisting of bounding boxes, class labels, and confidence scores for all recognized objects within the frame. These detections are stored and used to generate annotated images with overlaid bounding boxes.

A filtering step is applied at the image level to reduce unnecessary output on the operator user interface. While all the images with detected objects are preserved in the backend results, only images containing at least one detected living object are forwarded to the web-based detection viewer. This filtering reduces visual clutter and prioritizes relevant scene information for the operator.

Processed images with detection overlays are saved to an output directory and made accessible to the viewer interface. The web viewer retrieves these images and displays them alongside detection metadata, including object class labels and associated confidence values.

Processing Steps:

1. Images are uploaded to the incoming_images/ directory via the image receiver API.
2. The YOLO processing server monitors the directory for new files.
3. Detected images are processed using the YOLO11s model to generate bounding boxes and labels.
4. Images containing at least one living object are selected for display.
5. Annotated images are saved and served to the web viewer.

### 4.5.3 MASt3R-SLAM Pipeline

The MASt3R-SLAM subsystem is responsible for generating a 3D reconstruction of the environment using the images collected by the device. This pipeline operates on the same dataset as the object detection system, using images stored in the incoming_images/ directory.

The system runs the image_receiver_api.py script in continuous mode using the --continuous flag. In this mode, the pipeline periodically checks for newly received images and incrementally updates the reconstruction model. This allows the system to refine the 3D model over time as additional images are captured and uploaded.

As part of the preprocessing, newly received images are converted into PNG format to ensure compatibility with the MASt3R-SLAM pipeline. These images are then processed to estimate camera poses, including position and orientation, by identifying and matching gesture points across multiple views. Using these estimated poses, the system reconstructs the spatial structure of the environment.

The reconstructed environment is further refined using Gaussian Splatting techniques to generate a dense and visually coherent 3D model. Once a reconstruction cycle is completed, the updated model is exported and made available to the web-based viewer. This process repeats at configurable time intervals, allowing the model to be continuously updated as new data becomes available.

While image_receiver_api.py runs in continuous mode:

1. New images in “incoming_images” are converted into png formats
2. New png versions of images are processed for model generation, interpolating points and estimating camera position and orientation based on anchor points in collected images
3. Once model generation is complete, the completed model is uploaded to the web viewer where it can be freely viewed by the user
4. This process repeats periodically based on configured wait time, effectively keeping the model on the viewer as up to date as possible

### 4.5.4 Web-based viewer

The system includes a web-based interface to provide intuitive control and visualization without requiring technical expertise. The interface is hosted on a central server and accessible via web browser over a secure Tailscale connection. The interface provides direct control over camera client on Raspberry Pi using only a couple of buttons that can be pressed to start and stop capture. When activated, the interface sends an http request to the API endpoint, which triggers the corresponding action on Raspberry Pi.

To provide real-time feedback, the interface includes a system status indicator that reflects the current state of the pipeline:

- Loading
- Ready
- Processing

The interface displays outputs for both 3D reconstruction (via Master slam and Gaussian splatting pipeline) and object detection (via YOLO annotations overlaid on captured images)

## 4.6 Testing

A full end-to-end test to simulate real use:

1. Use a room with furniture, doorways, obstacles, people (if possible)
2. Connect battery to device and wait for it to join network
3. Operator has Viewer open and presses “start capture”
4. Tester rolls ball into the room from outside the doorway
5. Operator monitors incoming images being sent in
6. When enough time has passed that satisfies operator, operator presses “stop capture”
7. Model generates after 45-70 seconds
8. Once the model is ready, operator uses Viewer to identify
  a. Room layout
  b. Primary obstacles
9. On top right corner, operator presses “detections” to view all images with object detection annotations

## 4.7 Future Considerations

4.7.1 Software

3D Gaussian Splatting requires a large number of images to be captured from different angles in order to achieve an accurate model. When our device is rolled, there are an insufficient number of images and angles. Future work should explore alternate reconstruction methods that can handle this issue.

Another area of improvement is the image capture and transmission pipeline. The current approach relies on discrete image capture followed by http-based uploads, which introduces latency and limits overall throughput to the server. A more efficient method could improve data transfer rates and reduce delays in processing. Increasing throughput would improve both reconstruction accuracy and real time responsiveness.

The system could also be improved by enabling a live camera feed once the ball is done rolling. Once the ball is at rest, the Raspberry Pi could switch from burst image capture to continuous video streaming, allowing the operator to observe the environment in real time. This would provide immediate situational awareness before 3D reconstruction is complete.

The user interface and control architecture could also be improved. Currently, the start/stop controls in the web interface are linked with camera initialization, leading to increased startup latency. Decoupling the start/stop capture buttons on the Viewer could reduce startup time and allow near instant activation of capture when operator issues command.

4.7.2 Hardware

Due to budget constraints, using multiple independent microcontrollers ensures true simultaneous and parallel processing in order to improve capture rate. A multi-cam adapter operates cameras sequentially rather than simultaneously. A true simultaneous setup such as a Quadrascopic Stereo Camera or a Synchronized Stereo Camera would be too expensive ($225-240 per unit).

For the power supply, ensuring that all wiring and cables fit well within the enclosure is critical for reliability and durability. One solution used is a right angle charging cables, which reduced strain on connectors and improved internal cable routing.

The choice of operating system of each microcontroller must align with the software libraries and dependencies required for the system pipeline. For example, object detection frameworks, such as Ultraanalytics, are not compatible with older operating systems such as Raspberry Pi OS Bullseye. Future implementations should standardize on operating systems that support current libraries and toolchains, ensuring compatibility with Slam,object detection, or other processing tasks.

4.7.3 Shell

The current shell could be improved by modifying it to be more spherical. A rounder design would ensure smoother and more predictable rolling. Additionally, reducing the number of screw threadings for the enclosure would reduce the maintenance time for assembling and disassembling. Expanding the internal volume would also be helpful to better accommodate wiring and cable connections.

The shell would also benefit from a more secure mounting solution for power supply to ensure it remains fixed and protected during operation. A dedicated compartment would prevent movement that may lead to disconnections or damage. It would also be helpful to incorporate easy access mechanisms (like a pin hole or a latch) to allow users to replace the battery without disassembling the shell.

# 5 Experimental results (5-10 pages; 20 points)

This section is also very important, as it shows whether or not your project worked. You should provide:

- A description of the tests you performed to validate the system,
- Numerical results of these tests,
- A thorough analysis and discussion of these results, and
- A collection of pictures of your final system

## 5.1 Physical design

We used a scale and measuring tape to verify the weight and diameter of the ball was within the limit we set for it (7 inch for diameter and 1 lb for weight). This is to ensure that the ball is the perfect size and weight to easily roll the ball. The diameter of our ball ended up being 5.45 inches and the weight of the ball with all components ended up being 0.966 pounds (438 grams).

Measured

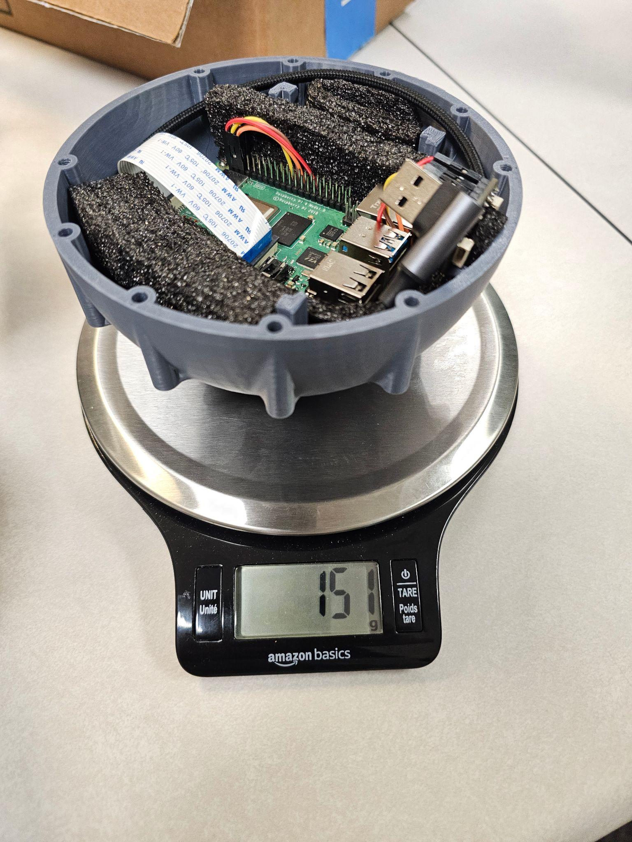
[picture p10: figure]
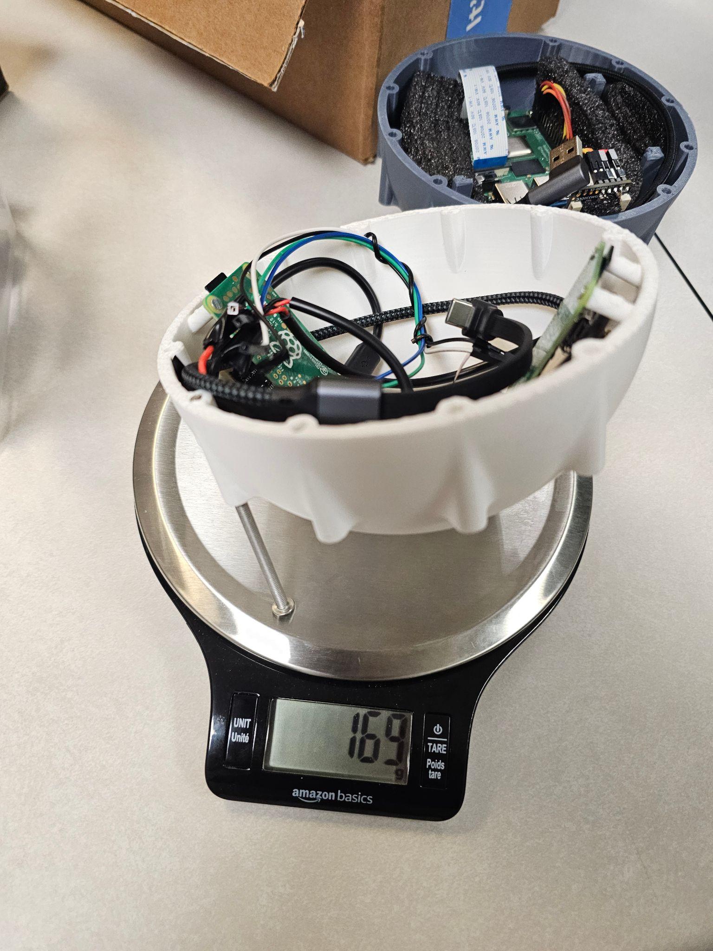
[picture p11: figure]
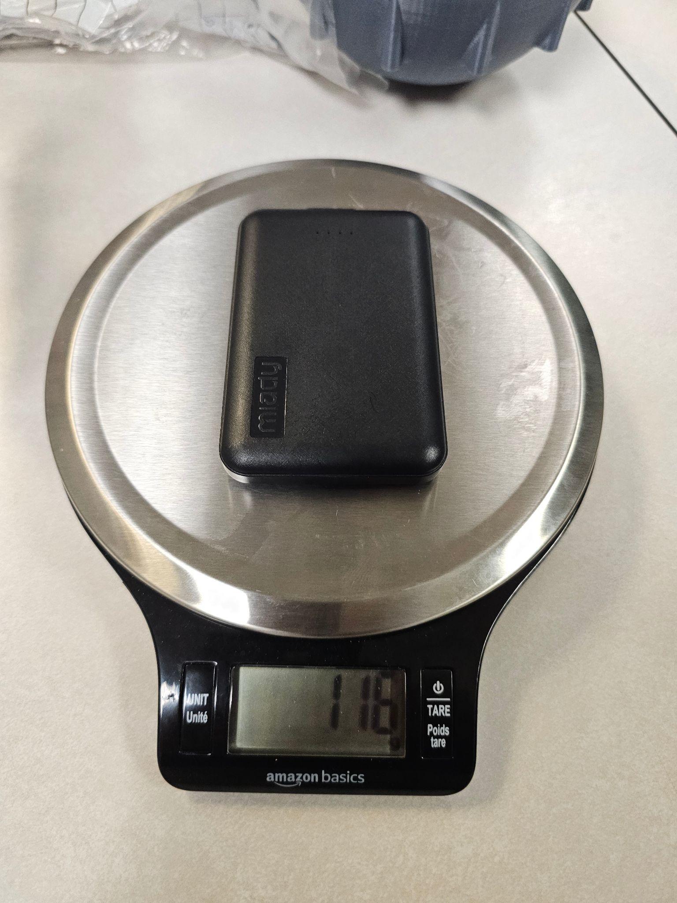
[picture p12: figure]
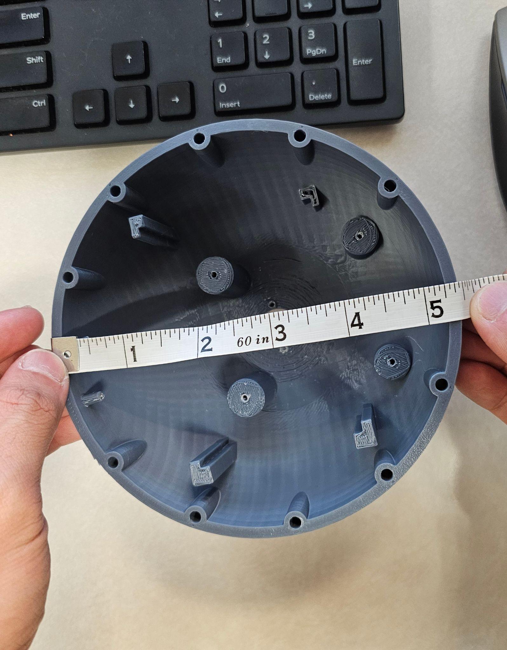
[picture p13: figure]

## 5.2 Multi-Camera Capture

We showed that the incoming_images folder is initially empty. We start capture while the ball is stationary as it is taking pictures. This allowed us to show the performance of the cameras without taking into account motion. We open the incoming_images folder and show that it has populated shortly after initialization, confirming that the cameras were actively capturing images and saving the data. The images clearly showed different perspectives of the same environment, demonstrating that the three cameras were properly oriented at distinct angles and functioning simultaneously. Timestamps are indicated to evaluate how fast the capture rate was.

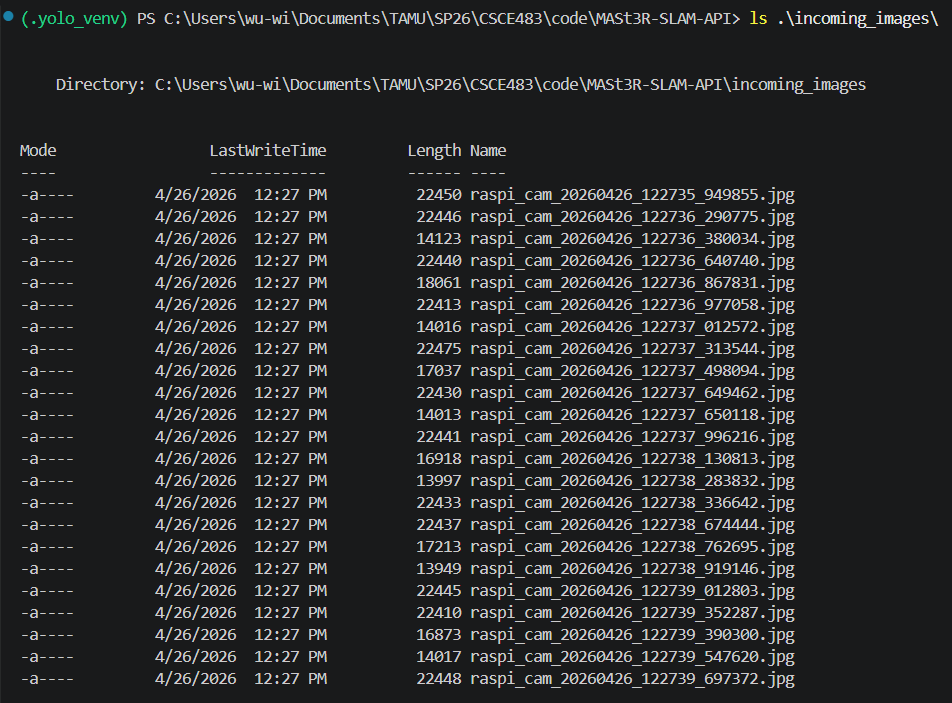
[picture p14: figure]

Figure 5.2: Console Log of the incoming images

Table 2: Image Capture Timing and Performance Summary

First image timestamp | 12:27:35.95
Last image timestamp | 12:27:39.70
Duration | 3.75s
Total image count | 23
Frames per second | 6.13

## 5.3 Gyroscope and Camera cutting

We ran 2 different tests to verify the gyroscope and camera-cutting functionality: one where the ball is handheld and another test where the ball is rolled as it would be in the real use-case. This test is meant to determine if the downward images can correctly be identified with the gyroscope. For handheld, the ball was manually positioned so that each camera, one at a time, was oriented downward toward the ground. During image capture, we monitored the terminal output to verify whether the system correctly identified the active downward-facing camera. This process was repeated for all three cameras to ensure consistent behavior across the full camera array. The results showed that, in each case, the terminal correctly indicated when a camera was facing downward, confirming that the IMU-based orientation detection was functioning as intended in a controlled environment.

For rolling, the ball was placed on the ground, and image capture was initiated before rolling the ball across a short distance. This test introduced real-world motion and rotation, allowing us to evaluate the system under more realistic deployment conditions. After stopping the capture process, we examined the contents of the incoming_images folder. Each image was opened and visually inspected to determine whether it was facing downward. We then compared this observation with the corresponding filename metadata, which encodes orientation information.

As a result, downward detection reduces downward images by 40% without limiting useful data.

Table 5.3: Orientation Detection Performance Metrics

Metric | Description | Count
True Positive (TP) | Correctly detects the downward-facing orientation | 2
False Positive (FP) | Incorrectly labels a non-downward orientation as downward | 0
False Negative (FN) | Fails to detect when device is actually facing downward | 3
True Negative (TN) | Correctly identifies non-donward orientations | 21

## 5.4 SLAM Modeling and YOLO Object Detection

Using only one camera, we start capturing and have one person walk around a room holding the ball to take images. We only had one camera on to reduce the complexity of multi-camera inputs. Slow movement allows for better image overlap and improves the accuracy of the reconstruction process. When done capturing, the 3D model will show up on the viewer. Then, we open the object detections indicated by a button to see all of the images the camera took with object detection annotations.

As a result, the 3D model was able to get a good amount of the room if the person is slowly walking around. The reconstructed model was able to capture a good amount of tables, people at the tables, objects on the tables, and even some of the walls. Object detection was able to correctly identify people. However, it can sometimes have some inaccuracies when detecting inanimate objects such as mixing up TVs, doors, & monitors as well as chairs & couches due to how similar they look.

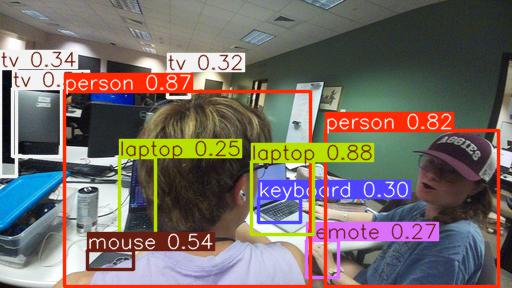
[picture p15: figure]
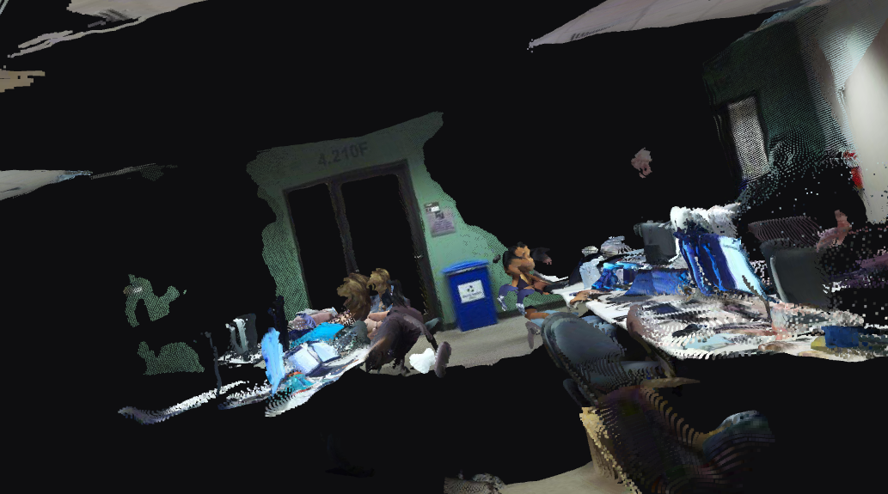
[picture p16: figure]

Figure 5.4.1: SLAM Modeling Figure 5.4.2: YOLO Object Detection

Table 5.4: Master SLAM Timing Measurements

Events | Time Elapsed (s)
GUI button pressed, First image captured | 6
Image capture duration | 0.15
First image upload -> Server received image | 0.2
Server receives first image -> server receives enough images to generate model | 10
Model generation duration | 45-70
Client receives and parses model | 3
Total | ~1:05-1:30 minutes

## 5.5 Camera Performance in a low-light environment

Because we did not have access to anything that could mimic a smoky environment, we were only able to test in low light conditions. We used the same testing procedure as in the previous test: A user walked slowly around the room while holding the ball and capturing images using a single camera. However, for this test, the room lights were turned off, leaving only a small amount of light entering from outside the room. This created a high-contrast environment with both dimly lit and near-dark regions.

After completing image capture, the reconstruction pipeline was executed, and the resulting 3D model was displayed in the viewer. Object detection results were then examined through the annotation interface. As a result, the 3D model only included portions of the room that were illuminated by the incoming light, while areas in complete darkness were not reconstructed. This indicates that the reconstruction algorithm relies heavily on visible features and sufficient lighting to extract meaningful spatial information. Object detection was able to successfully identify objects in the room despite being in dark regions.

This test showed a clear limitation that the system requires adequate lighting in order to generate an accurate 3D model.

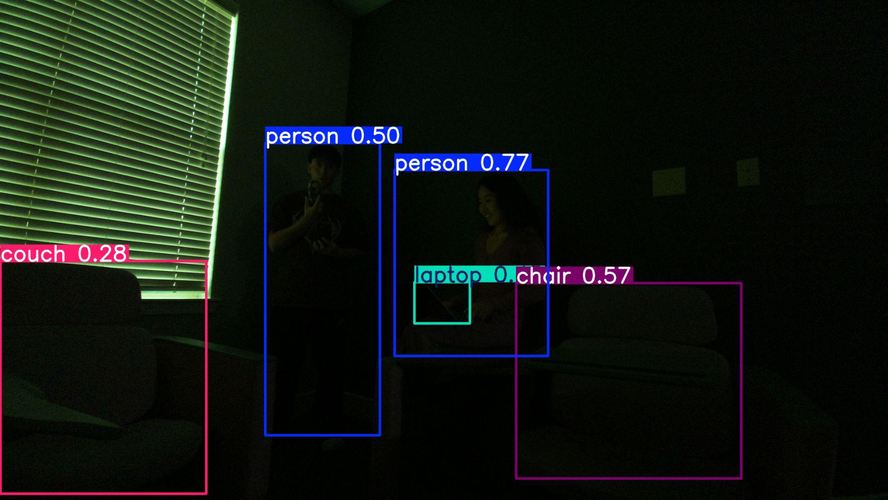
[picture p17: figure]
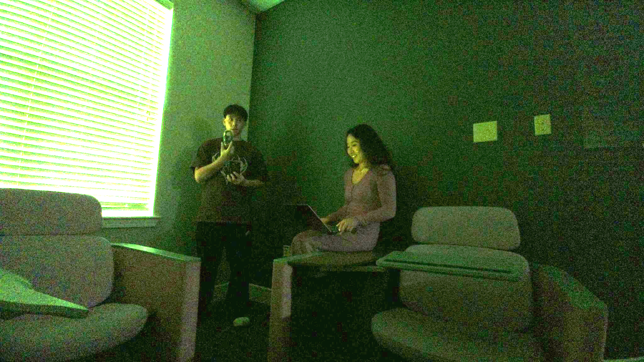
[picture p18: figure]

Figure 5.5.1: Adjusted Contrast & Brightness for Figure 5.5.2: Original Image with Detections

verification of correct detections

## 5.6 End-to-End System Functionality

Evaluating the overall performance of the system, we conducted a test that combined all major subsystems, including image capture, camera orientation handling, 3D reconstruction, and object detection, under realistic deployment conditions. The goal of this test was to simulate how the system would perform in an actual use case, where the ball is deployed by rolling it into an environment with people present. We started capture and then rolled the ball in a room with one person inside. This introduced rapid motion, varying orientations, and non-uniform image capture intervals. After the rolling motion was complete, image capture was stopped, and the collected data was processed through the reconstruction pipeline. The resulting 3D model was then viewed using the system’s visualization interface. Object detection results were also examined through the annotated image viewer.

As a result, the 3D model contained only a limited representation of the room, with large portions either missing or poorly defined. This was primarily due to the fact that images captured during rolling were relatively sparse and taken from rapidly changing perspectives, resulting in insufficient overlap between consecutive frames. The object detection continued to perform effectively. Despite the reduced number of usable images and the motion-induced variability, the system was still able to accurately identify key objects within the captured frames. This demonstrates that object detection is more robust to motion and sparse data compared to the 3D reconstruction process.

Overall, this test shows that the system was unable to create a 3D reconstruction of a room from rolling the ball into that room. In order to get an accurate result of the model, the ball must be handheld and slowly moved around the room, which ultimately defeats the purpose of this project.

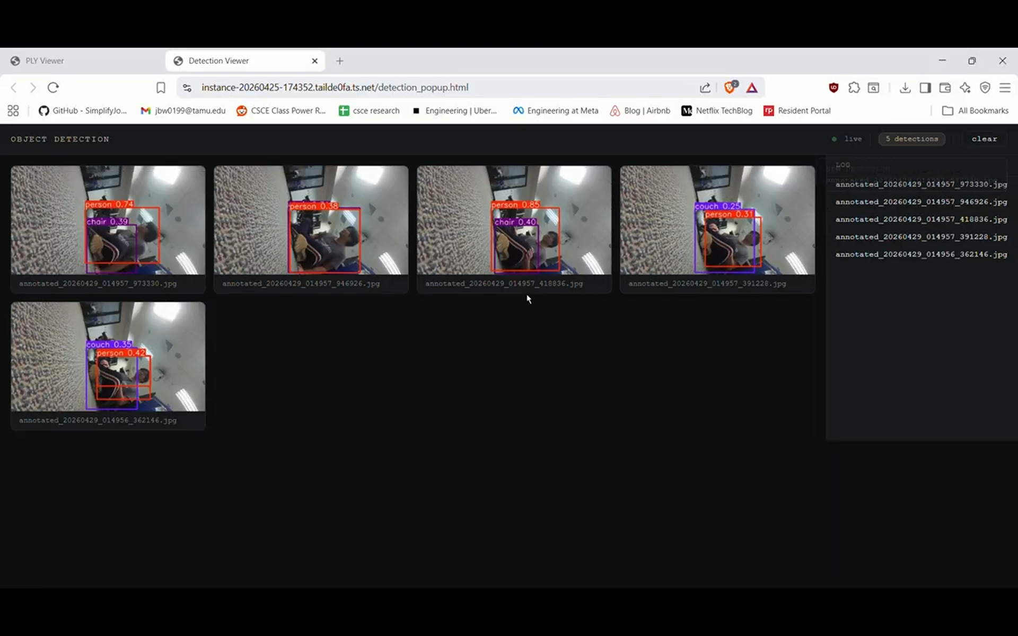
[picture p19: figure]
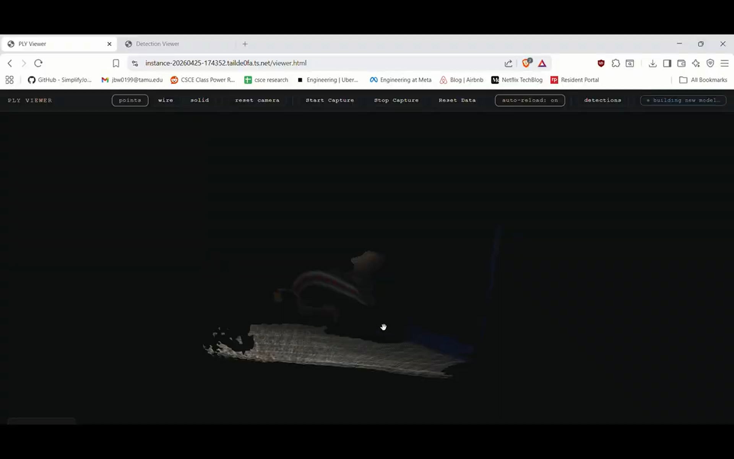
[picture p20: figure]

Figure 5.6.1: 3D Reconstruction Figure 5.6.2: Detections Tab with Object Detections

# 6 User’s Manuals (5-10 pages; 20 points)

This document should contain detailed (1) hardware installation, (2) software installation, and (3) operation instructions for the users of your product(s). It should be aimed at the “average user” of your system (please identify the characteristics of such user) and should not require that the reader be an engineering professional.

6.1 Introduction

The Emergency Response Mapping Sphere is a tactical device designed to provide situational awareness before entering unknown indoor environments. After being deployed into the room, the device automatically captures a 360 view, streams encrypted data, and creates a 3D model of the space. This tool helps reduce risk for first responders operating in unknown rooms, collapsed buildings, and other dangerous structures. The system requires no engineering knowledge and relies on a simple web-based interface.

6.2 Safety information

Warnings:

- Avoid heat, fires, and high temperature environments unless using a certified fire resistant shell
- Roll ball only into rooms, not directly at people
- Use a controlled roll to avoid bouncing (roll it like a bowling ball)
- Keep away from water and corrosive liquids

Safety operation practices:

- Check surroundings before rolling
- Maintain a secure grip when preparing to roll
- Do not deploy near explosives or chemicals

6.3 Intended User Profile

This product is intended for first responders such as firefighters and police officers, not civilian use.

Assumed skill level:

- Comfortable using a laptop
- No requirement for engineering or programming skills

Operating conditions:

- Unknown rooms
- Collapsed structures
- Disaster areas
- Debris zones and low visibility spaces

6.4 Package contents

Package should include

- 1 Emergency Response Mapping Sphere
- 1 charging brick with power interface
- 1 USB-C charging cable
- User manual

6.5 System overview

Once powered on and deployed,

1. Device boots in 45 seconds
2. Must manually press Start/Stop Capture on Viewer on a web browser
3. Master slam and Gaussian Splat 3D model is created, as well as Object Detection annotations
4. Model is shown on Viewer
5. Allow pan, zoom, and rotate interaction
6. Object detection annotation can be viewed on Viewer by pressing “detections” button

Connection uses:

1. WiFi with VPN encryption
2. Local server software
3. Manual device ID pairing

6.6 Hardware Installation

Physical specifications

- Shape: sphere
- Diameter: 5.45 inches (7 in max set by us)
- Weight: 0.996 pounds (1 lb max set by us)
- Material: ABS filament (3D printed/CAD design)

Internal components:

- 1 Raspberry Pi 4B microcomputer
- 2 Raspberry Pi Zero 2 W microcomputer
- 3 NoIR (No IR filter) Camera modules
- Portable USB battery bank
- Gyroscope module (Camera-cutting)
- CMTPD Board (Power distribution)
- Foam cushion

Durability:

- Designed for short-ranged tactical rolls
- Avoid excessive force to prevent bounces or other unpredictable behavior

6.7 Charging and Power

Charging instructions

1. Connect USB-C cable to charging block
2. Insert cable into power outlet
3. Charge until full (3-4 hours)
4. Put charging block back into appropriate place and screw the shell back together

Powering On

- Device powers when battery is connected
- No power button
- Boot time: ~45 seconds

Powering Off: disconnect battery cable

6.8 Software Installation

System Requirements

- Laptop running Windows/macOS
- Wi-Fi capability
- Local Administrator permissions

Installation Steps

1. Download Local Server Program

2. Run the Installer and follow the prompts

3. Start the program

4. The browser interface opens automatically

6.9 Device Pairing

1. Open the Viewer on web browser
2. Ssh into Pis based on its Tailscale IP address
3. Enter login credentials

6.10 Operation of Product

Step-by-Step Deployment

1. Charge the device fully
2. Connect the battery cable (device turns on)
3. Wait ~45 seconds for boot
4. Open web UI
5. Press button “start capture” on Viewer, which initializes camera client on Pi
6. Roll device like a bowling ball into target room
7. Press “stop capture” when ball stops rolling
8. View the model on the laptop

Viewer

- Model displayed after ~45-70 seconds
- Use the mouse to:
  - Rotate view
  - Zoom
  - Pan
- To view object detection annotations: press the “detections” button at top right corner. This will open up all the object detection images in a new tab.

Connection uses:

- Wifi with VPN encryption
- Local server software
- Manual device ID pairing

6.11 Interpolating 3D Model

The device uses Master Slam and Gaussian Splat modeling.

Viewer features

1. Start/Stop capture button
2. 3D space visualization
3. Object detection annotations

Lighting conditions

- Low light or reflective surfaces may reduce clarity
- Disconnect if storing long term

6.12 Maintenance

Shell inspection

After heavy impact

- Check shell for cracks
- Replace shell if damaged

Cleaning

- Wipe with dry cloth
- Avoid solvents
- Do not submerge

Storage

- Room temperature storage
- Avoid sunlight/heat
- Charge fully before storing

Battery Care

- Use only included charger
- Disconnect if storing long term

6.13 Technical specifications

Table 6.13: System Technical Specifications

Feature | Specification
Diameter | 5.45 in
Weight | 0.996 lb
Shell material | ABS filament
Boot time | ~45 seconds
Reconstruction | Master slam and gaussian splatting
UI | Local web interface
Encryption | VPN

6.14 Troubleshooting

Table 6.14: Common Issues and Troubleshooting Solutions

Problem | Cause | Solution
Device hot | High temp | Remove battery, let it cool
No connection | Pi not connected | Reboot the Pi
Device not powering on | Battery is dead | Recharge battery
Poor 3D model | Low light or fast motion | Improve lighting or move slower
Camera not working | Loose camera ribbon cable | Reattach the ribbon cable
Images not uploading | Network failure | Restart device and verify server connection
3D model not created yet | Model has not finished generating | Wait 45-70 seconds

# 7 Course debriefing (2-4 pages; 10 points)

This document should contain the group’s collective answers to the following issues.

Provide a thorough discussion of your team management style. If you were to do the project again, what would you do the same, what would you do differently?

Are there any particular safety and/or ethical concerns with your product(s)? What steps did your group take to ensure these concerns were addressed? Are there any additional steps you would have taken if you were to do the project again?

Did you test your product(s)? Do they work as proposed? Can you think of any relevant situations in which you haven’t tested your product(s)? If you were to do this project again, what additional verification and testing procedures might you add?

Similar to the predecessor team, our management style began somewhat loosely structured at the start of the semester. The key difference however, was that we established a team lead whose primary responsibility was to evaluate each member’s strengths, weaknesses, and preferred areas of work before delegating responsibilities. This allowed us to split the team into two primary subteams. The hardware subteam focused on physical design and electronics integration, and the software subteam was responsible for embedded capture pipeline, networking, and server-side reconstruction. The intent was to ensure that each member was working in the area where they could contribute most effectively and that both subsystems could progress concurrently.

In practice, this structure worked well early in the semester, with everyone contributing to the improved hardware and software system designs. In addition, both subteams also had a primary lead to delegate further tasks and gauge cross-subteam dependencies. However, as the project progressed, the subteam boundaries became less defined. Some members found themselves contributing to both hardware and software tasks simultaneously or having to pick up other subteam member’s tasks, creating an uneven distribution of workload that was not always recognized or rebalanced in time. Moreover, there was a consistent pattern of significant prerequisite tasks not being completed on time, which introduced substantial downstream delays in testing and key implementation milestones such as MAST3R-SLAM integration. A particularly costly example was the 3D-printed enclosure not being designed and printed until very late into the project, which also required lab clearance and printing time. This directly cost the team approximately two weeks of potential testing and integration time. There were also tasks that showed no demonstrable progress both inside and outside of the weekly team meeting throughout the semester. The issue was compounded by the fact that the team did not establish formal accountability mechanisms early enough, so by the time the lack of contribution and uneven task completion became apparent, there was limited time and leverage to correct it.

If we were to redo the project again, we would keep the practice of appointing a team lead and splitting into subteams early, as this proved to be a genuine advantage over a fully informal approach. What we would do differently is implement strict, formal progress tracking from the very beginning of the semester, defining deliverables per member at each weekly checkpoint and an explicit expectation that incomplete or absent progress would be called out immediately rather than quietly absorbed by the rest of the team. Relying on teammates to self-manage without enforcement proved costly, and a future team in this position should not hesitate to escalate non-contribution issues early, whether to the team lead, instructor, TA, or all. Establishing this level of accountability from the beginning would have allowed us to address participation issues before they escalate into consistent critical delays on hardware that the entire system depended on.

Our project involved working with multiple electronic components and power sources, and the most significant safety concern we countered was also related to the power supply. During extensive testing, we observed on multiple occasions that the battery overheated significantly under load. Because a single battery was responsible for powering all three microcontrollers, with two of them drawing current simultaneously through a shared power distribution board connected directly to the battery, the thermal load exceeded what the battery could safely sustain during prolonged operation. The consequences of this were significant: the overheating caused SD card corruption across all three Pi microcontrollers, requiring each one to be fully reimaged before testing could resume. There were also frequent difficulties of the Pi attempting connection or sustaining initial connection to the network. While no fire occurred, the temperature reached during these incidents were concerning enough to treat it as a genuine fire safety hazard.

This introduces a clear ethical concern as well. A device intended for deployment in life-critical first responder scenarios carries an elevated standard of reliability. A battery that overheats under normal operating conditions does not only risk damaging the device itself but also introduces the possibility of a fire hazard in the very environments the device is intended to be thrown into, which could directly endanger the responders relying on it. Releasing or deploying such a product with a known thermal risk without resolving it would be ethically unacceptable. To address this concern, we immediately removed the battery and replaced it with a stronger battery to be used during extensive testing and did research on what went wrong. If we were to do this project again, we would conduct thorough thermal and power testing under realistic load conditions much earlier in the development cycle before any extended integration testing begins. We would also enforce a strict component vetting process to ensure that any battery used is rated for the combined sustained load of all connected components, with appropriate safety margins built in. One practical application would be to simulate the full hardware system using circuit simulation software prior to physical assembly and ordering, in order to gauge power consumption, validate component ratings, and verify overall specs before committing to a physical build.

We performed testing across all major functional components of the system, and while the core features operated as implemented, not all results met the original performance requirements established at the start of the project, particularly in the context of a real first-response deployment scenario. Object detection performed reliably and exceeded expectations, achieving a high rate of success across all demonstration trials, correctly identifying people even under partial occlusion, detecting small body parts such as legs, and functioning effectively in low-light environments. Camera-cutting logic driven by the gyroscope functioned correctly under slower, stable motion, but became unreliable at higher speeds or first-response scenarios due to consecutive frames sharing too few overlapping features, contributing to inaccurate model generations. The end-to-end pipeline latency, measured from the ball rolling to serving the 3D model, failed significantly short of the sub-30 second target. During demos, the pipeline averaged over a minute to complete in all scenarios, tossing or rolling the device into a well-lit or low-visibility room. However, we were unable to test in scenarios that involved smoke-filled rooms, extreme temperatures, or just throwing the ball due to how fragile the internal components were. After investigation, we determined that the 3D reconstruction step alone from MAST3R-SLAM, is an irreducible computational bottleneck that cannot be accelerated below roughly 45 seconds given our own hardware setup. This is a fundamental system limitation and future iterations would need to evaluate lighter-weight reconstruction methods or more power dedicated hardware to address it. Other system limitations identified through testing include the server’s data ingestion throughput being insufficient to keep pace with the full frame rate of the three Pis simultaneously, and the inability to check battery status without physically opening the shell. If we were to do this project again or start back earlier, we would introduce more rigorous performance benchmarking earlier in the development cycle to identify the latency and reconstruction quality gaps. Testing the system under more realistic deployment conditions such as actual throws, varied lighting, and multi-room environments, would also be a priority in future iterations.

# 8 Budgets (2-4 pages; 5 points)

Summarize the costs of the prototype, including parts list with sources, and any support tools required (with costs.) Provide (1) detailed cost breakdowns, (2) a short narrative summarizing the costs, and (3) a comparison of these costs with the proposed budget and with your estimate of the cost in mass production.

## 8.1 Detailed Cost Breakdown

The total prototype cost for the emergency response mapping sphere is approximately $249.95. Table 8.1 summarizes the complete bill of materials, including all major hardware components and supporting materials required for system assembly.

Table 8.1: A parts list of materials that are needed to build the design.

| Amount | Cost per Unit ($) | Total Amount ($)
Raspberry Pi 4B, 2GB RAM | 1 | 59.50 | 59.50
Raspberry Pi Zero 2W 512MB RAM | 2 | 15.00 | 30.00
Raspberry Pi Camera Module 3 Wide Noir | 3 | 38.50 | 115.50
Adafruit ST ISM330DHCX 6-DOF IMU | 1 | 19.95 | 19.95
Power Bank | 1 | 9 | 9
3D-printer filament (ABS, 1 kg) | 1 | ~6 | ~6
Misc. fasteners, heat-shrink, etc. | - | ~10 | ~10
Total Cost | | | 249.95

Total Estimated Cost: $249.95

## 8.2 Cost Narrative

The primary cost driver of the system is the multi-camera setup required for 3D reconstruction. The Raspberry Pi Camera Module 3 Wide NoIR units account for the largest portion of the budget due to the need for three synchronized imaging nodes. The computing hardware, consisting of one Raspberry Pi 4B and two Raspberry Pi Zero 2 W units, is the second major cost component and supports distributed image capture across the device.

This architecture replaced the original multiplexer-based design, which increased hardware cost but improved performance by enabling parallel image capture. Additional costs include the IMU for orientation tracking, a power bank for portable operation, and low-cost structural materials such as 3D printing filament and fasteners.

Overall, the system was implemented within a constrained prototype budget while meeting the required functionality for imaging, transmission, and processing.

## 8.3 Budget Comparison and Mass Production Estima

The system was designed under a budget constraint of $250 or less, which served as the primary cost target throughout development. The final prototype cost of $249.95 meets this requirement while still satisfying all functional requirements.

The largest contributor to cost is the multi-camera configuration required for 3D reconstruction, followed by the distributed computing setup using multiple Raspberry Pi devices. The transition from a multiplexer-based design to independent processing nodes increased hardware costs but improved system performance by enabling parallel image capture.

In a mass production scenario, the cost is expected to decrease due to bulk purchasing and hardware optimization. The estimated production cost per unit is approximately $180–$220, primarily driven by reduced pricing of camera modules and embedded computing components at scale.

# 9 Appendices

Here you can include any additional information not already in the implementation notes (e.g., detailed circuit schematics, class hierarchy) that would help replicate or maintain your implementation.

# 10 References

Here you acknowledge all the documents that you used as references throughout the text. Please use the IEEE reference format.

https://ieeeauthorcenter.ieee.org/wp-content/uploads/IEEE-Reference-Guide.pdf

TAMU CSCE 483 Final Report /

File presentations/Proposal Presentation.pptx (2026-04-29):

## Emergency Response Mapping Sphere

Team ERMS
Brandon Le, Kiet Nguyen, Hai Yen Nguyen, Antony Quach, Josh Wu

## Problem Background

- Emergency response operations require rapid, accurate situational awareness in hazardous environments.
- First responders routinely enter dangerous, unfamiliar environments with limited visibility.
- This increases the risk of injury, delayed rescue, and poor tactical decisions.
- Existing technologies, such as drones, body-worn cameras, and robots often provide incomplete or unreliable information.
- Current technologies do not sufficiently reduce operational risk due to impracticality to deploy in confined or chaotic events.

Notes: First responders routinely enter dangerous and unfamiliar environments with limited situational awareness, increasing the likelihood of injury, delayed rescue, and poor tactical decision-making.

Existing technologies, such as drones, body-worn cameras, and robots are often not good enough for current situations, and do not significantly reduce risks for first responders.

## Needs Statement

From 2018-2020, 87% of firefighter injuries occurred in structure fires. Active shooter incidents last only 12 minutes on average. There is a need for a device that first responders can use to ensure safety quickly in hazardous environments.
The Emergency Response Mapping Sphere needs improved sensing, mapping quality, and information delivery for reliable use in real-world emergency environments.
Current Limitations:
- 3D Mapping: Limited accuracy and resolution of the mapped out environment, reducing reliability of spatial information
- Information Delivery: Data is not presented in an intuitive way, slowing decision-making under stress
https://www.usfa.fema.gov/statistics/reports/firefighters-departments/firefighter-injuries-v22i4.html
https://apps.usfa.fema.gov/pdf/efop/efo248128.pdf

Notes: While a previously developed throwable environmental scanner has demonstrated the ability to improve situational awareness for first responders, significant limitations prevent effective use in real-world emergency environments. In particular, the sensing and camera modules in prior implementations perform poorly in low-visibility environments such as dark or smoke-filled spaces.

Additionally, current limitations in the accuracy and resolution of the generated 3D environment reduce the reliability of spatial information needed for informed decision-making. Inaccurate or incomplete information undermines the core purpose of the system and may increase operational risk rather than reduce it.

Beyond sensing performance, situational data must be presented to first responders in a reliable and intuitive manner that enables rapid understanding and effective decision-making under high-stress situations.

There is therefore a need to enhance the environmental sensing, 3D mapping quality, and information delivery of the Throwable Environment Scanner so it can perform reliably.

## Goal and Objectives

- Enhance the Emergency Response Mapping Sphere to deliver high-quality 3D mapping on a mobile device
- Uses onboard cameras to stream video and reconstruct a 3D environment for improved threat detection
- Maintains portability and durability:
  - 3 lb max, 7 inch diameter max
  - Withstands drops and collisions
- Minimum 5-minute
- Maximum 10-minute continuous operation
- Cost constraints:
  - $250 max for design iterations


## Literature Review

Solution | Description | Pros | Cons
The Brinc Ball | Throwable communication device that functions as a telephone | Capable of communicating with people inside dangerous area | Does not record video, scan environments, or generate maps
Bouncing Image Explorer 360 | Throwable 360° tactical ball camera with live phone streaming (WiFi & Cellular) | Compact, durable, and capable of window impact deployment | No depth reconstruction (manual viewing only); high cost ($4k–$7k)
Squishy Robotics Stationary Robot | Aerial-deployable multi-sensor response device with 360 camera | Highly impact-tolerant; designed for hazardous and disaster environments | Stationary operation; complex and high-cost system

## Literature Review

Solution | Description | Pros | Cons
Recon Robotics Throwbot | Compact wheeled surveillance robot for live video and audio | Extremely durable (30-ft drops, 120-ft throws) and provides instant video & audio of environment | Requires training to operate and has only one camera angle
Flyability Elios 3 (Surveying Payload) | Collision-tolerant indoor drone designed for inspection, mapping, and 3D environment reconstruction | Can actively navigate complex or obstructed spaces | Not throwable, requires skilled operation, and is high-cost industrial hardware

## Design Constraints and Feasibility

Performance Requirements
- 3D model generation must complete in ﹤30 seconds from capture to visualization, requiring GPU-accelerated SLAM and Gaussian Splatting on remote server
- System must achieve ﹤5 seconds end-to-end latency (capture to operator display) through efficient compression and stable WiFi transmission
- Hardware needs to synchronize 3 camera feeds within ﹤100 ms via multiplexer while simultaneously processing IMU data and transmitting it to remote server
- Object detection must identify moving targets with ≥85% accuracy
Durability Requirements
- Device must survive repeated 2-meter drops and continuous rolling without component damage
- Maximum weight of 3 lbs for comfortable one handed throwing
Cost Requirement
- Prototype cost should be within $150-$250, with a sub $75 unit cost for mass production

## Evaluation of alternative solutions

Drones
Pros
- Provide overhead views of environments, including inaccessible or elevated areas.
- Already commercially available and supported by existing technology.
Cons
- Hard to operate in enclosed areas
- Requires significant skill from a trained operator

Ground Robots
Pros
- Can have mobility in enclosed areas
- A lot of them carry very sophisticated mapping and recording systems
- Already being used by some first responders and military units
Cons
- Mobility issues if the ground is obstructed/uneven
- Usually large and hard to carry. Not very portable

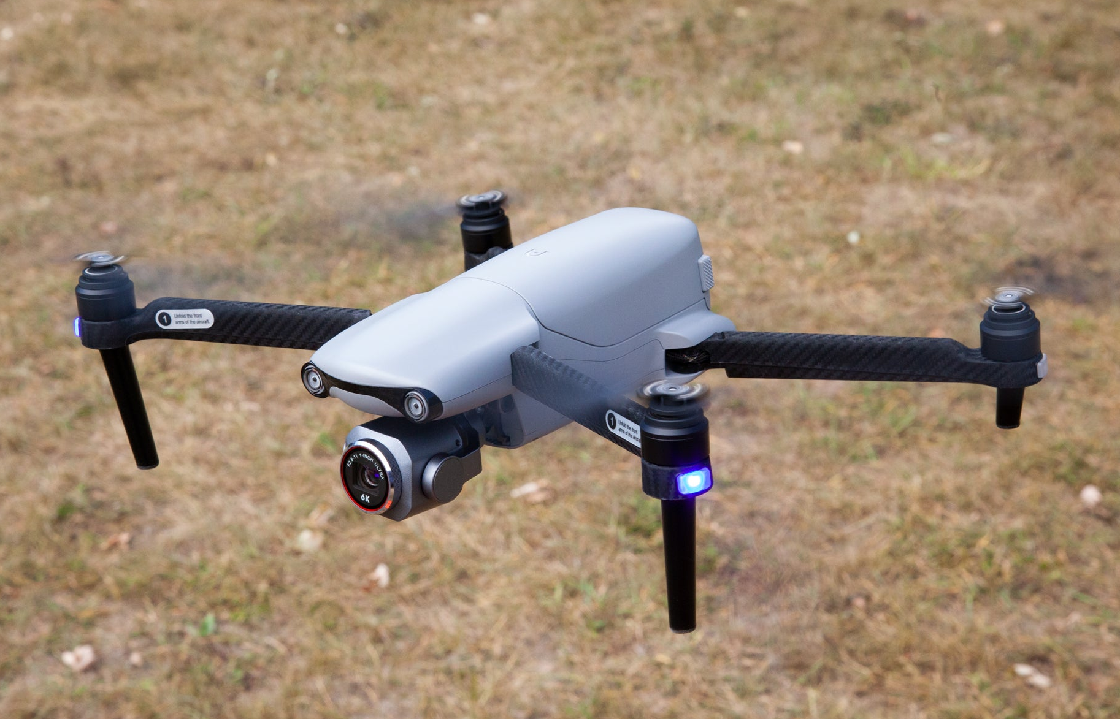
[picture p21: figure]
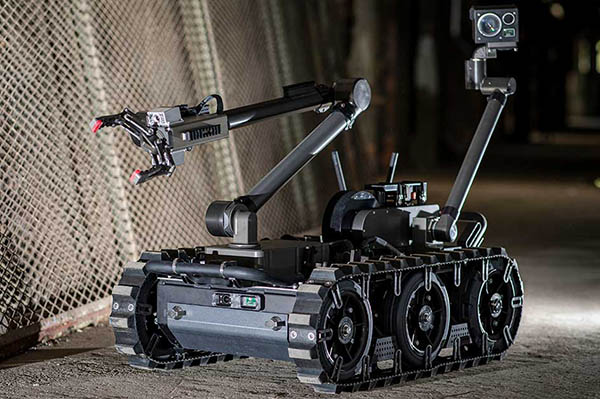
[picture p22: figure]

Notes: Drones

Pros
Provide overhead views of environments, including inaccessible or elevated areas.
It can be equipped with high-resolution cameras and thermal imaging.
Already commercially available and supported by existing technology.
No humans are put in harm's way

Cons
Hard to operate in enclosed areas
Requires significant skill from a trained operator
Not easily repairable
biggest drawback to drones is that they are very hard to place into rooms that are not easily accessible. Therefore, they are basically unusable in most scenarios that our product shines
Ground Robots

Pros
No humans are put in harm's way
Some have decent mobility
A lot of them carry very sophisticated mapping and recording systems (LIDAR, cameras, infrared)
Already being used by some first responders and military units

Cons
Mobility issues if the ground is obstructed/uneven
Usually large and hard to carry. Not very portable
Very costly to purchase and to maintain. Many of these are still in the prototype stage.

## Evaluation of alternative solutions

Wearable Cameras for First
Responders
Pros
- Portable, lightweight
- High-quality streaming of real-time events
Cons
- A human has to enter room to get the images
- Only video streaming

Throwable Communication Ball
Pros
- Portable, lightweight, durable
- Connects first responders to civilians
Cons
- Requires someone within the room to speak to
- Only helps for audio, not for mapping environment

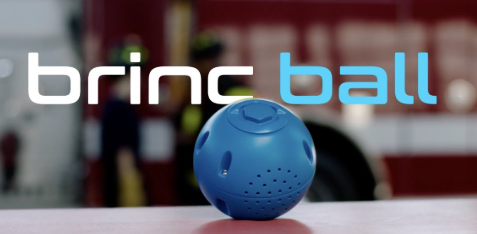
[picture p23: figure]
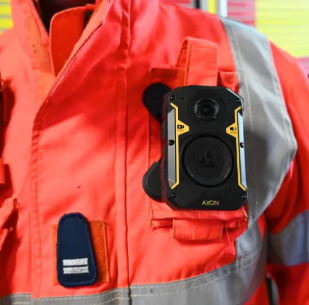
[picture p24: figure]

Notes: Drones

Pros
Provide overhead views of environments, including inaccessible or elevated areas.
It can be equipped with high-resolution cameras and thermal imaging.
Already commercially available and supported by existing technology.
No humans are put in harm's way

Cons
Hard to operate in enclosed areas
Requires significant skill from a trained operator
Not easily repairable
biggest drawback to drones is that they are very hard to place into rooms that are not easily accessible. Therefore, they are basically unusable in most scenarios that our product shines
Ground Robots

Pros
No humans are put in harm's way
Some have decent mobility
A lot of them carry very sophisticated mapping and recording systems (LIDAR, cameras, infrared)
Already being used by some first responders and military units

Cons
Mobility issues if the ground is obstructed/uneven
Usually large and hard to carry. Not very portable
Very costly to purchase and to maintain. Many of these are still in the prototype stage.

## Proposed Design: Overview


- A throwable ball containing cameras and electronics can be tossed into an environment
- Once deployed, the ball captures wide-angle photos from each camera and transmits them to remote server via TAMU IoT
- Once received by server, it synchronizes the data and performs 3D reconstruction via 3D Gaussian Splatting
- Resulting 3D model sent to connected device for operator to inspect

## Proposed Design: Overview


Monitoring Unit

## Hardware Design: Throwable Ball


Battery→Pi (Initializing power source)
Raspberry Pi→Camera Multiplexer→Cameras

Physical Shell: 3D-printed/CAD Design
(ABS filament for temperature resistance)
Components:
- Raspberry Pi 4B microprocessor
- Camera multiplexer
- 3 Camera modules
- Portable USB battery bank
- IMU Sensor (For camera-cut alg)
Overview
- Cameras connected to Pi via Multiplexer
- IMU Sensor connected to Pi
- All components powered by a portable battery bank through the Pi
- Cameras and Pi are mounted by screws

## Software Design: Server Connection

Network Architecture
- Tailscale VPN Mesh Networking
  - Secure encrypted tunnel between ball and server
  - Works across different physical Wi-Fi networks
Data Transmission
- From Ball to Server
  - Synchronized camera frames (JPEG compressed)
  - IMU orientation data
  - Timestamps for frame alignment
  - HTTP Post via FastAPI endpoint
- From Server to Operator
  - WebRTC streaming of rendered 3D model
  - Real-time visualization updates


Server process image

Ball

Remote Operator navigates 3D scene

## Software Design: SLAM + 3D-Mapping

Step 1: SLAM (Simultaneous Localization and Mapping)
- Estimates camera position and orientation for each frame
- Uses IMU data to improve pose estimation accuracy
- Tracks ball’s trajectory through the environment
Step 2: 3D Gaussian Splatting
- Reconstructs environment
- Refines geometry based on SLAM-estimated camera poses
- Generates photorealistic 3D scene
Step 3: Object Detection & Threat Identification
- YOLO (You Only Look Once) based method
- Flags moving objects

Server

Ball

Render image


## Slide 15

## Software Design: Camera Multiplexing

For most orientations, one camera will be pointing downwards, rendering it ineffective. We can disable the downward camera
Requires two components:
- A gyroscope to determine orientation
- A camera adapter to multiplex multiple cameras to one board
Reduces power consumption, wear on cameras, and points of failure

## Approach for design validation

Camera Capture & Identification
Verify image accuracy by comparing console output to actual room layouts
Wireless Data Transmission
Test video and mapping streams through barriers up to 10 m for latency and data loss
User Interface & Display
Evaluate responsiveness and ease of use through operator trials and feedback
Durability & Impact Resistance
Perform repeated 10-ft drop tests; system must remain fully functional
Mapping & Decision Algorithms
Validate 3D model accuracy by benchmarking against real room measurements

## Economic analysis and budget

Item | Quantity | Unit Cost (USD) | Total (USD)
Raspberry Pi 4 Model B, 1GB | 1 | 38.50 | 38.50
Raspberry Pi Camera Module 3 Wide | 3 | 37 | 111
Inertial Measurement Unit | 1 | 5 | 5
Anker Power Bank 5V/3A | 1 | 20 | 20
Multi Camera Adapter Module | 1 | 50 | 50
3D-printer filament (ABS, 1 kg) | 1 | 11 | 11
Solder | - | 5 | 5
Wire spool (22–24 AWG) | 1 | 3 | 3
Misc. fasteners, heat-shrink, etc. | - | ~5 | ~5
Estimated total | | | 248.50

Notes: https://www.amazon.com/Anker-Travel-Ready-Technology-High-Speed-Output%EF%BC%88Black%EF%BC%89%EF%BC%8C1pack/dp/B0D5CLSMFB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

## Schedule of tasks


## Project management & teamwork

Hardware & CAD Designing
Antony & Kiet
>Antony: Team Lead
>Kiet: Finance & Purchases
- Design inner mounting of cameras and pi board
- CAD design for shell modification
- Plan component connections
- Physical debugging
- Calculate capacity needs (power, etc)
- Document hardware assembly procedures

Software
Brandon (Computer Vision & SLAM)
>System Design Architect
- SLAM implementation
- 3D map generation + visualization
- Object-detection implementation
- Camera-cut algorithm
Hai Yen (Embedded Systems & UI)
>Testing Coordinator
- User interface design
- Sensor data processing
- Sensor calibration
Josh (Networking & Streaming Design)
>Technical Reporting & Documentation
- Real-time data processing
- Backend API management
- Camera feed synchronization

## Project management & teamwork

General Responsibilities
- Testing product via dropping, throwing, rolling
- Debugging
- Documentation
  - Personal notebook on general progress, thoughts, tasks
  - Documenting respective specialized role for other team members to use for referencing cross-dependency tasks and timeline
(Ex: Embedded Systems and Hardware team for debugging sensors feed)
Management
- Weekly meetings and agenda for updating progress status and upcoming tasks
- Primary communication: Discord with dedicated channels for hardware, software, testing, sharing useful links and notes
- Task and progress tracking: Github for all coding documentation and changes, Spreadsheets for team’s overall task progress and individual tasks to ensure transparency

## Societal, Safety & Environmental Analysis

Societal Impact
- Enhances first responder safety and mission success in hazardous environments
- Enables faster, more informed emergency decisions through real-time 3D situational awareness
- Low cost and lack of need for training enables rapidly deployable safety at scale
Safety Considerations
- Battery protection circuitry prevents electrical hazards such as overheating, overcharging, and short-circuiting
- Remote operation capability limits direct human exposure to dangerous environments
Environmental Considerations
- Compact 3D-printed shell minimizes the material waste and enables rapid prototyping
- Energy-efficient electronics freduce power consumption and extend battery life

## Questions?

## THANK YOU

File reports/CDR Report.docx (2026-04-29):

Emergency Response Mapping Sphere


Critical Design Review

Team ERMS

Brandon Le

Kiet Nguyen

Hai Yen Nguyen

Josh Wu

Antony Quach

Department of Computer Science

Texas A&M University

March 25, 2026

Table of Contents (Be sure to regenerate before submitting).

1 Introduction (1 page; 5 points) 2

2 Proposed design (5-10 pages; 60 points) 4

2.1 Updates to the proposal design (if applicable) 4

2.2 System description (1-2 pages; 30 points) 5

2.3 Complete module-wise specifications (4-6 pages; 30 points) 5

2.3.1 Ball Hardware 5

2.3.2 Ball Electronic Connections 6

2.3.3 Raspberry Pi Selection 7

2.3.4 Camera Cutting Algorithm 7

2.3.5 Camera Multiplexing 7

2.3.7 Connectivity 8

2.3.8 Ball to Server Dataflow 8

2.3.9 Live Object Detection 8

2.3.10 Gaussian Splatting 8

2.3.11 Server to Operator Dataflow 9

3 Project management (3-5 pages; 30 points) 10

3.1 Updated implementation schedule (1 page; 10 points) 10

3.2 Updated validation and testing procedures (1 page; 10 points) 11

3.3 Updated division of labor and responsibilities (2 pages; 10 points) 13

4 Preliminary results (1-2 pages; 5 points) 13

4.1 Smoke Environment Camera Validation 13

5 References 16
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

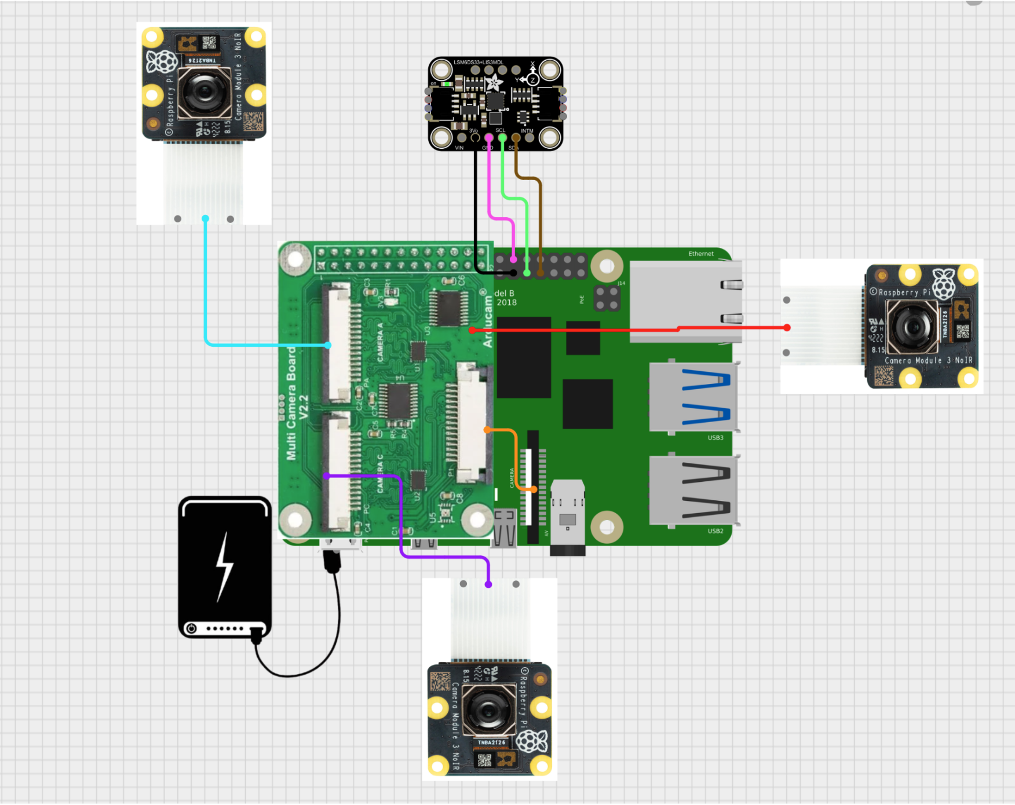
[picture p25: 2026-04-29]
designs/schematics/Initial Schematic (1 Pi).png

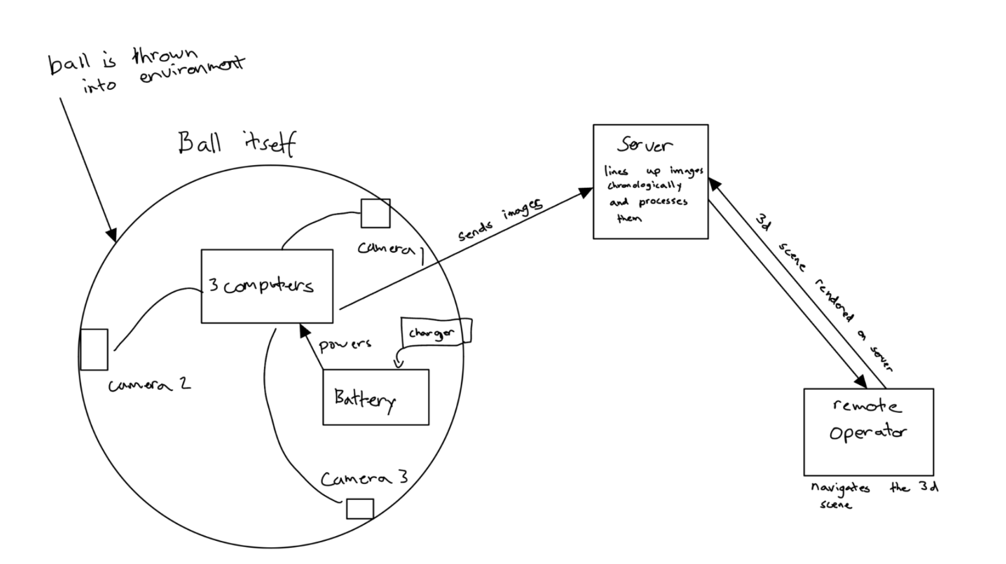
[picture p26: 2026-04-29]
designs/schematics/INITIAL System Level Description 2.png

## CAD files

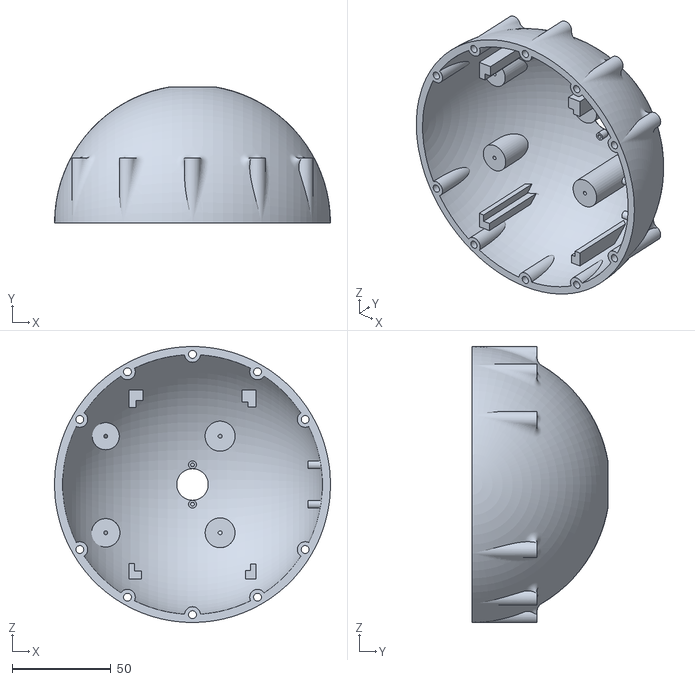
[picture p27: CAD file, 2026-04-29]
designs/schematics/3d printing/Final Design/Ball_bot_features_v2.STL
140.0 x 69.0 x 140.0

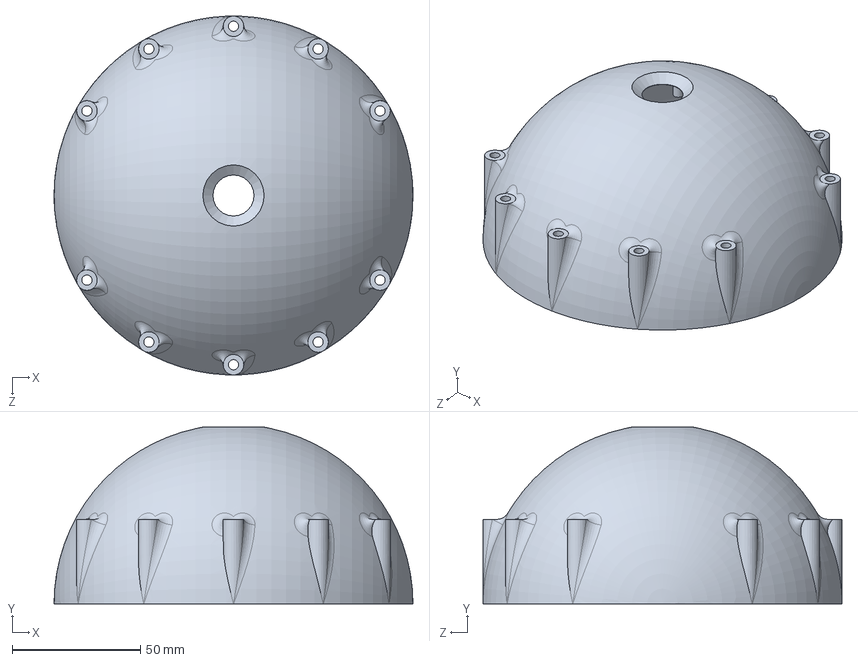
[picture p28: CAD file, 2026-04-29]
designs/schematics/3d printing/Initial Design/Ball_bot_features.SLDPRT
140.0 x 69.0 x 140.0 mm

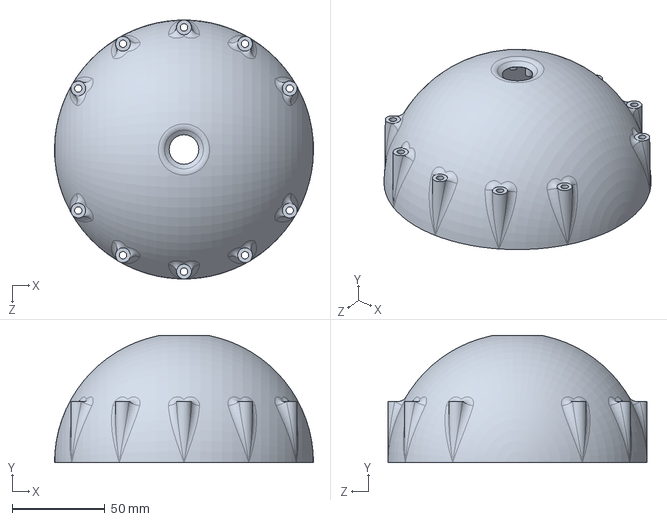
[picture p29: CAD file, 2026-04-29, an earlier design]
designs/schematics/3d printing/Previous Team/Ball.SLDASM
140.0 x 68.7 x 140.0 mm

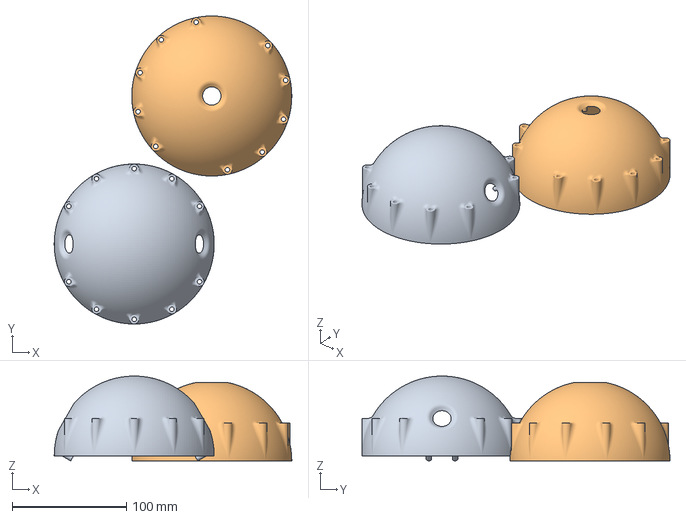
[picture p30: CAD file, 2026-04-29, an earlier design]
designs/schematics/3d printing/Previous Team/Ball2.3mf
207.9 x 269.5 x 74.3 mm

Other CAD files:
designs/code/erms-object-detection/viewer_test/model.ply
designs/schematics/3d printing/Final Design/FINAL Ball.SLDPRT
designs/schematics/3d printing/Previous Team/Body 03 (9).SLDPRT
designs/schematics/3d printing/Initial Design/Ball_bot_features.STL
designs/schematics/3d printing/Previous Team/Ball.x_t

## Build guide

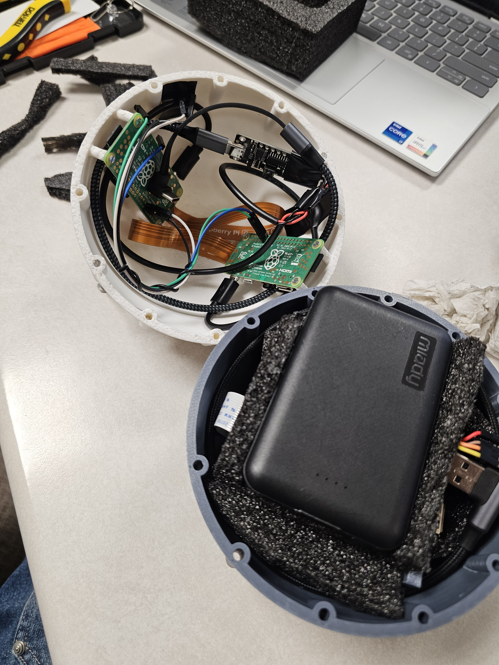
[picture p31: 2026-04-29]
designs/Hardware System Visuals & Measurements/Final System Assembly/20260423_022814.jpg

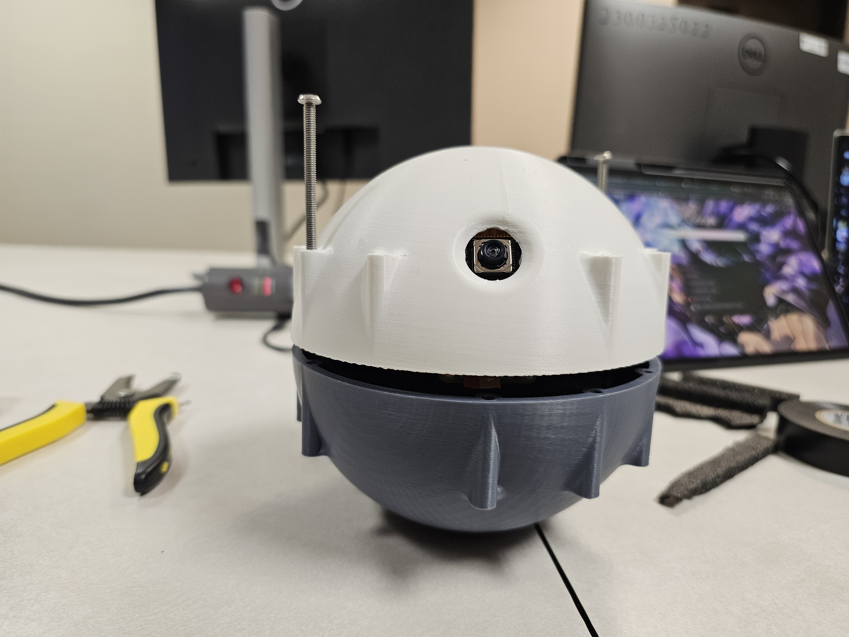
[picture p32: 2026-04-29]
designs/Hardware System Visuals & Measurements/Final System Assembly/20260423_013412.jpg

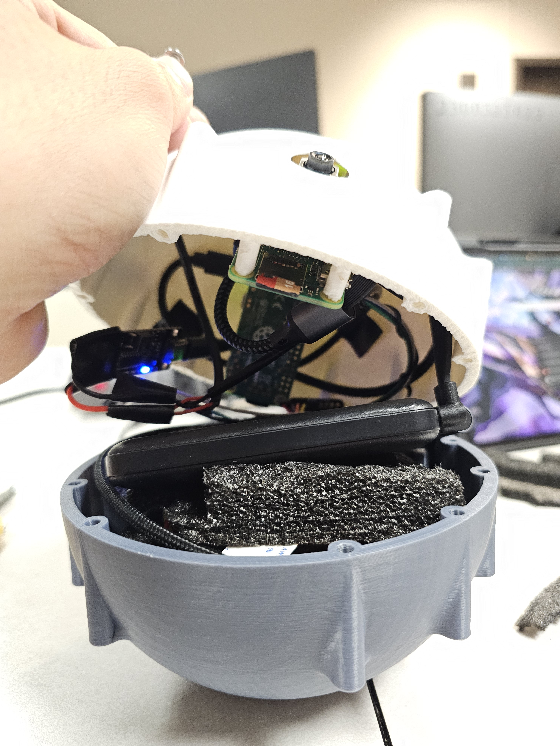
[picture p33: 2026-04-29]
designs/Hardware System Visuals & Measurements/Final System Assembly/20260423_013419.jpg

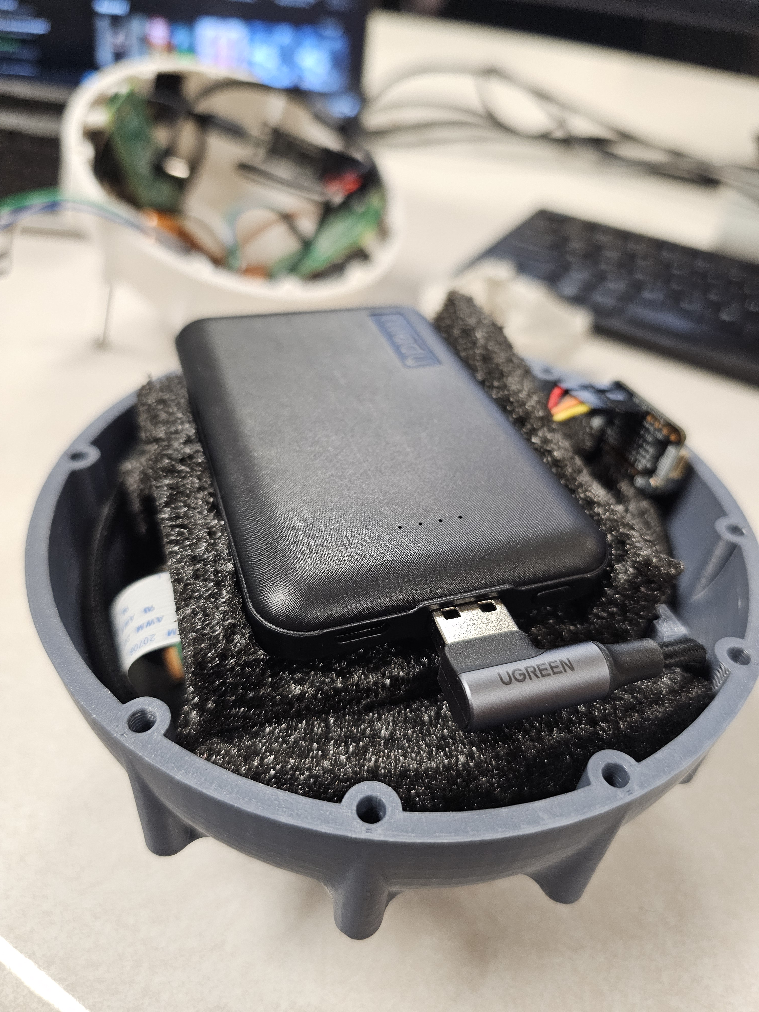
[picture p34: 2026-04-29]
designs/Hardware System Visuals & Measurements/Final System Assembly/20260423_022739.jpg

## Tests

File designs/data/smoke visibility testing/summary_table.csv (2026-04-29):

Lighting | Smoke Density (sticks) | Camera | Contrast (CDI) | Sharpness | Edges
dark | 0 | noir | 0.5556 | 2.46 | 0
dark | 0 | regular | 0.6667 | 2.36 | 0
dark | 1 | noir | 0.7429 | 2.64 | 461
dark | 1 | regular | 0.7674 | 2.41 | 0
dark | 3 | noir | 0.5135 | 2.6 | 899
dark | 3 | regular | 0.6 | 2.38 | 0
dark | 5 | noir | 0.4865 | 2.66 | 1055
dark | 5 | regular | 0.5814 | 2.41 | 0
dark | 7 | noir | 0.525 | 2.74 | 1261
dark | 7 | regular | 0.5833 | 2.43 | 0
dark | 9 | noir | 0.4783 | 2.68 | 1553
dark | 9 | regular | 0.5556 | 2.39 | 0
dark | 11 | noir | 0.449 | 2.76 | 737
dark | 11 | regular | 0.4915 | 2.36 | 0
light | 0 | noir | 0.5556 | 13.77 | 26087
light | 0 | regular | 0.6186 | 10.53 | 24691
light | 1 | noir | 0.6309 | 6.7 | 20078
light | 1 | regular | 0.5844 | 9.58 | 22290
light | 3 | noir | 0.6239 | 7.41 | 23033
light | 3 | regular | 0.5556 | 9.62 | 25411
light | 5 | noir | 0.5726 | 5.83 | 19906
light | 5 | regular | 0.485 | 7.26 | 21092
light | 7 | noir | 0.5671 | 6.1 | 22715
light | 7 | regular | 0.4632 | 9.4 | 33191
light | 9 | noir | 0.4815 | 3.59 | 11033
light | 9 | regular | 0.3826 | 4.11 | 15041
light | 11 | noir | 0.4352 | 2.32 | 3466
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

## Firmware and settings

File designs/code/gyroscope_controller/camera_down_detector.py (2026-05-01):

"""
camera_down_detector.py
-----------------------
Determines whether any of 3 cameras (mounted on a rolling ball) is facing
downward, using raw accelerometer + gyroscope data from an IMU also mounted
on the ball.

Algorithm
---------
Orientation is tracked as a rotation matrix R (3x3, SO(3)) that maps vectors
from the IMU body frame into the world frame (world = z-up, gravity = -z).

Each timestep:
  1. Gyroscope integration  — rotate R by the measured angular velocity using
     a first-order Rodrigues step.  Fast but drifts over time.
  2. Accelerometer correction — when ||accel|| ≈ g (little linear acceleration),
     the accel vector is a noisy measurement of gravity in the body frame.
     We slerp R a small amount toward the orientation implied by that gravity
     vector.  Slow but drift-free.

Camera facing directions are stored as unit vectors in the IMU body frame.
Each step we rotate them into the world frame and check whether they point
close enough to world-down = (0, 0, -1).

Usage
-----
1. Instantiate CameraDownDetector once (before the polling loop).
2. Call detector.update(accel, gyro, dt) each polling iteration.
3. Read detector.cameras_facing_down for the result.

Configuration
-------------
CAMERA_DIRECTIONS_BODY : list of 3 unit vectors (body frame)
    Replace the default XY-plane vectors with your physically measured ones.
    Each vector must be a unit vector pointing in the direction the camera faces.

FACING_DOWN_THRESHOLD_DEG : float
    A camera is "facing down" when the angle between its world-frame direction
    and the world-down vector (0,0,-1) is less than this value.

ACCEL_CORRECTION_GAIN : float  (0 < gain < 1)
    How aggressively the accelerometer corrects gyro drift each step.
    Lower = trust gyro more (better during fast rolling).
    Higher = track gravity faster (better when slow).

ACCEL_TRUST_TOLERANCE : float  (m/s²)
    Accelerometer correction is only applied when
    | ||accel|| - g | < ACCEL_TRUST_TOLERANCE.
    Keeps correction disabled during strong linear / centripetal acceleration.
"""

import numpy as np
from typing import Tuple, List


# ---------------------------------------------------------------------------
# Configuration — edit these to match your physical setup
# ---------------------------------------------------------------------------

# Camera facing directions as unit vectors in the IMU body frame.
# Default: 3 cameras evenly spaced (120° apart) in the IMU XY-plane.
# Replace with your measured vectors; they do NOT need to lie on a major plane.
CAMERA_DIRECTIONS_BODY: List[Tuple[float, float, float]] = [
    (0.005076, 0.997434, 0.071414),  # Camera 0
    (0.434201, -0.586046, 0.684120),  # Camera 1
    (-0.434202, -0.400043, -0.807115),  # Camera 2
]

# Angular tolerance: a camera is "facing down" if it is within this many
# degrees of the world-down direction (0, 0, -1).
FACING_DOWN_THRESHOLD_DEG: float = 20.0

# Complementary filter gains
ACCEL_CORRECTION_GAIN: float = 0.02   # per-step slerp weight toward accel estimate
ACCEL_TRUST_TOLERANCE: float = 1.0    # m/s² — how close to 9.81 to trust accel

# Standard gravity
G: float = 9.80665  # m/s²


# ---------------------------------------------------------------------------
# Helpers
# ---------------------------------------------------------------------------

def _normalize(v: np.ndarray) -> np.ndarray:
    """Return the unit vector of v, or v unchanged if it is near-zero."""
    n = np.linalg.norm(v)
    return v / n if n > 1e-9 else v


def _rodrigues(axis: np.ndarray, angle_rad: float) -> np.ndarray:
    """
    Rodrigues' rotation formula: 3x3 rotation matrix for rotating
    `angle_rad` radians about unit vector `axis`.
    """
    axis = _normalize(axis)
    c, s = np.cos(angle_rad), np.sin(angle_rad)
    t = 1.0 - c
    x, y, z = axis
    return np.array([
        [t*x*x + c,   t*x*y - s*z, t*x*z + s*y],
        [t*x*y + s*z, t*y*y + c,   t*y*z - s*x],
        [t*x*z - s*y, t*y*z + s*x, t*z*z + c  ],
    ])


def _rotation_from_gravity(accel_body: np.ndarray) -> np.ndarray:
    """
    Compute a rotation matrix R such that R @ accel_body_normalized ≈ (0,0,-1)
    (world-down direction).  The yaw component is unconstrained and set to 0.

    This is used only for initialization and for the accelerometer correction
    direction — it does NOT directly overwrite R; we slerp toward it.
    """
    down_body = _normalize(-accel_body)       # gravity pulls down; accel reads up
    world_down = np.array([0.0, 0.0, -1.0])

    # Rotation axis and angle from down_body → world_down
    axis = np.cross(down_body, world_down)
    sin_angle = np.linalg.norm(axis)
    cos_angle = np.dot(down_body, world_down)

    if sin_angle < 1e-9:
        # Already aligned (or exactly opposite)
        if cos_angle > 0:
            return np.eye(3)
        else:
            # 180° flip — pick an arbitrary perpendicular axis
            perp = np.array([1.0, 0.0, 0.0])
            if abs(down_body[0]) > 0.9:
                perp = np.array([0.0, 1.0, 0.0])
            return _rodrigues(perp, np.pi)

    axis = axis / sin_angle
    angle = np.arctan2(sin_angle, cos_angle)
    return _rodrigues(axis, angle)


def _slerp_rotation(R_current: np.ndarray,
                    R_target: np.ndarray,
                    t: float) -> np.ndarray:
    """
    Spherical linear interpolation between two rotation matrices.
    t=0 → R_current, t=1 → R_target.
    Implemented via the relative rotation's axis-angle.
    """
    R_rel = R_target @ R_current.T          # relative rotation
    # Extract axis-angle from R_rel
    angle = np.arccos(
        np.clip((np.trace(R_rel) - 1.0) / 2.0, -1.0, 1.0)
    )
    if abs(angle) < 1e-9:
        return R_current
    sin_a = np.sin(angle)
    axis = np.array([
        R_rel[2, 1] - R_rel[1, 2],
        R_rel[0, 2] - R_rel[2, 0],
        R_rel[1, 0] - R_rel[0, 1],
    ]) / (2.0 * sin_a)
    R_step = _rodrigues(axis, t * angle)
    return R_step @ R_current


# ---------------------------------------------------------------------------
# Main class
# ---------------------------------------------------------------------------

class CameraDownDetector:
    """
    Tracks ball orientation using a gyroscope-primary complementary filter
    and reports which cameras (if any) are currently facing downward.

    Parameters
    ----------
    camera_directions_body : list of 3-tuples, optional
        Unit vectors for each camera's facing direction in the IMU body frame.
        Defaults to CAMERA_DIRECTIONS_BODY defined at the top of this file.
    facing_down_threshold_deg : float, optional
        Angular tolerance in degrees for "facing down". Defaults to
        FACING_DOWN_THRESHOLD_DEG.
    accel_correction_gain : float, optional
        Per-step slerp weight for accelerometer correction (0–1).
    accel_trust_tolerance : float, optional
        m/s² window around g within which accel correction is applied.
    """

    def __init__(
        self,
        camera_directions_body: List[Tuple[float, float, float]] = None,
        facing_down_threshold_deg: float = FACING_DOWN_THRESHOLD_DEG,
        accel_correction_gain: float = ACCEL_CORRECTION_GAIN,
        accel_trust_tolerance: float = ACCEL_TRUST_TOLERANCE,
    ):
        dirs = camera_directions_body or CAMERA_DIRECTIONS_BODY
        if len(dirs) != 3:
            raise ValueError("Exactly 3 camera directions are required.")

        # Store camera unit vectors in body frame as (3,3) array, one row each
        self._cameras_body = np.array([
            _normalize(np.array(d, dtype=float)) for d in dirs
        ])

        self._threshold_cos = np.cos(np.radians(facing_down_threshold_deg))
        self._gain = accel_correction_gain
        self._trust_tol = accel_trust_tolerance

        # Orientation estimate: maps body → world.  Initialised to identity;
        # will be set properly on the first update() call.
        self._R: np.ndarray = np.eye(3)
        self._initialized: bool = False

        # Public outputs (updated every call to update())
        self.cameras_facing_down: List[bool] = [False, False, False]
        self.camera_world_directions: List[np.ndarray] = [
            np.zeros(3) for _ in range(3)
        ]

    # ------------------------------------------------------------------
    # Public API
    # ------------------------------------------------------------------

    def initialize_from_stationary(
        self,
        accel: Tuple[float, float, float],
    ) -> None:
        """
        Bootstrap the orientation estimate from a single stationary reading.
        Call this once before the polling loop begins, while the ball is still.

        Parameters
        ----------
        accel : (ax, ay, az) in m/s²
            Accelerometer reading while the ball is completely stationary.
        """
        accel_np = np.array(accel, dtype=float)
        self._R = _rotation_from_gravity(accel_np)
        self._initialized = True

    def update(
        self,
        accel: Tuple[float, float, float],
        gyro: Tuple[float, float, float],
        dt: float,
    ) -> List[bool]:
        """
        Process one IMU sample and update which cameras face downward.

        Parameters
        ----------
        accel : (ax, ay, az) in m/s²
            Raw accelerometer reading.
        gyro : (gx, gy, gz) in rad/s
            Raw gyroscope reading.
        dt : float
            Time elapsed since the last call, in seconds.

        Returns
        -------
        List[bool]  — same object as self.cameras_facing_down
            cameras_facing_down[i] is True if camera i is within
            facing_down_threshold_deg of straight down.
        """
        accel_np = np.array(accel, dtype=float)
        gyro_np  = np.array(gyro,  dtype=float)

        # --- Bootstrap if update() is called before initialize_from_stationary
        if not self._initialized:
            self._R = _rotation_from_gravity(accel_np)
            self._initialized = True

        # --- 1. Gyroscope integration (Rodrigues step) --------------------
        angle = np.linalg.norm(gyro_np) * dt
        if angle > 0.075 * dt:
            R_gyro = _rodrigues(gyro_np, angle)
            # Gyro is measured in body frame; rotate R from the right
            self._R = self._R @ R_gyro.T  # R_new = R_old · R_delta^T maps body→world

        # --- 2. Accelerometer correction ----------------------------------
        accel_mag = np.linalg.norm(accel_np)
        if abs(accel_mag - G) < self._trust_tol:
            R_accel = _rotation_from_gravity(accel_np)
            self._R = _slerp_rotation(self._R, R_accel, self._gain)

        # --- 3. Re-orthogonalise R (prevents numerical drift) -------------
        self._R = self._reorthogonalize(self._R)

        # --- 4. Evaluate each camera -------------------------------------
        world_down = np.array([0.0, 0.0, -1.0])
        for i, cam_body in enumerate(self._cameras_body):
            cam_world = self._R @ cam_body
            self.camera_world_directions[i] = cam_world
            # dot product with world_down: 1.0 = perfectly facing down
            dot = float(np.dot(cam_world, world_down))
            self.cameras_facing_down[i] = dot >= self._threshold_cos

        return self.cameras_facing_down
    
    def calibrate_gyro_bias(self, imu, num_samples=500):
        """
        Call this while the ball is completely stationary at startup.
        Returns the bias vector to subtract from all future gyro readings.
        """
        samples = []
        for _ in range(num_samples):
            samples.append(imu.gyro)
        bias = np.mean(samples, axis=0)
        print(f"Gyro bias: {bias}")
        return bias

    # ------------------------------------------------------------------
    # Private helpers
    # ------------------------------------------------------------------

    @staticmethod
    def _reorthogonalize(R: np.ndarray) -> np.ndarray:
        """
        Project R back onto SO(3) via SVD to counter floating-point drift.
        Called every step; cheap for a 3x3 matrix.
        """
        U, _, Vt = np.linalg.svd(R)
        return U @ Vt


# ---------------------------------------------------------------------------
# Example usage / smoke test
# ---------------------------------------------------------------------------

if __name__ == "__main__":
    import time

    print("=== CameraDownDetector smoke test ===\n")

    detector = CameraDownDetector(
        facing_down_threshold_deg=20.0,
        accel_correction_gain=0.02,
        accel_trust_tolerance=1.0,
    )

    # Simulate: ball is stationary, camera 0 faces down.
    # If camera 0 is along +X in body frame and the ball is oriented so that
    # +X points downward, the accelerometer would read (−g, 0, 0) ≈ (−9.81,0,0)
    # because gravity pulls along −X in body frame → accel reads +X.
    # Wait — accel reads the reaction to gravity, so: accel = +g in the
    # direction opposite to gravity.  If gravity is along −X_body, accel = (+g, 0, 0).

    stationary_accel = (G, 0.0, 0.0)   # gravity along −X_body → camera 0 faces down
    detector.initialize_from_stationary(stationary_accel)

    print("Initial state (stationary, camera 0 should face down):")
    # Pass zero gyro and tiny dt for a stationary reading
    result = detector.update(stationary_accel, (0.0, 0.0, 0.0), dt=0.01)
    for i, facing_down in enumerate(result):
        angle = np.degrees(np.arccos(
            np.clip(np.dot(detector.camera_world_directions[i],
                           [0, 0, -1]), -1, 1)
        ))
        print(f"  Camera {i}: facing_down={facing_down}  "
              f"(angle to down = {angle:.1f}°)")

    print("\nSimulating 90° roll (rotating around Z-axis at 1 rad/s for ~1.57s):")
    dt = 0.01
    steps = int(np.pi / 2 / (1.0 * dt))   # 90° at 1 rad/s
    for _ in range(steps):
        # During roll: accel still ~g but now with some centripetal component
        # For simplicity keep it as pure gravity (slow roll approximation)
        detector.update((G, 0.0, 0.0), (0.0, 0.0, 1.0), dt=dt)

    result = detector.update((G, 0.0, 0.0), (0.0, 0.0, 0.0), dt=dt)
    print("After 90° roll:")
    for i, facing_down in enumerate(result):
        angle = np.degrees(np.arccos(
            np.clip(np.dot(detector.camera_world_directions[i],
                           [0, 0, -1]), -1, 1)
        ))
        print(f"  Camera {i}: facing_down={facing_down}  "
              f"(angle to down = {angle:.1f}°)  "
              f"world_dir={detector.camera_world_directions[i]}")

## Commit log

2026-04-29 adding schematics datasheets data visuals
    [Ball.SLDASM, Ball.x_t, Ball2.3mf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]
2026-05-01 fix git submodules
    [calib.yaml, eval_calib.yaml, eval_no_calib.yaml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]
